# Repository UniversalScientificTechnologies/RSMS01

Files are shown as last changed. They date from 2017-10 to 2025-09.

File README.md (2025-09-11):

# RSMS01 – UHF Radio Storm Monitoring Station (with VLF trigger)

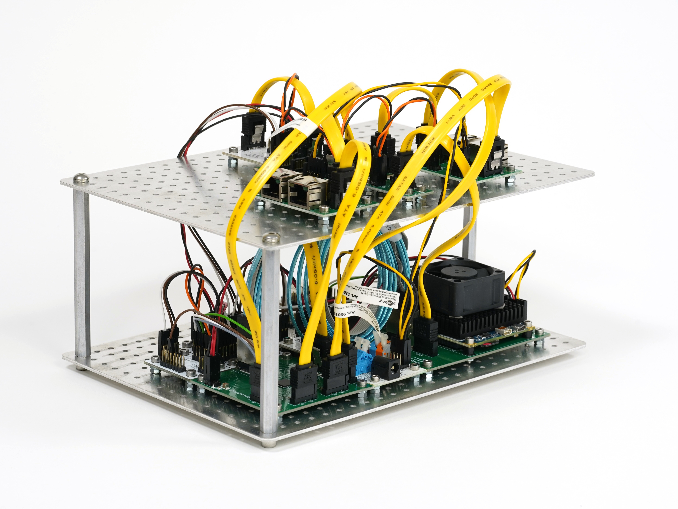
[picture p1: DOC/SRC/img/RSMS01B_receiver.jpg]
Lightning signal receiver RSMS01B UHF lightnig signal receiver RSMS01B


> Mobile/portable lightning receiver for research-grade event capture. Records a full 10 MHz RF segment around \~400 MHz from an antenna array, time‑stamped and triggered by a VLF front‑end. A closely related VLF station [RSMS02](https://github.com/UniversalScientificTechnologies/RSMS02) shares most subsystems.

## Overview

RSMS01 is a mobile UHF lightning observation station designed for ground deployments (rooftop platforms on vehicles, or fixed). It complements a VLF receiver ([RSMS02](https://github.com/UniversalScientificTechnologies/RSMS02)) used for robust triggering and coarse detection. Together, both instruments capture long, contiguous, time‑synchronized RF segments of lightning activity for detailed post‑processing (TDoA, interferometry/DOA, correlation to optical/EFM/radiation sensors).

Why **UHF + VLF**:

* **VLF ( 20 kHz  to 500 kHz):** strong from the main/lightning channel; excellent for reliable triggering and long‑range detection.
* **UHF (\~370–406 MHz):** rich in initial breakdown/leader structure; less contaminated by distant channel energy; ideal for fine‑scale timing/structure.

## Receiver Features

* **10 MHz contiguous RF capture** around \~400 MHz (tunable within local RFI constraints).
* **Antenna array** (4× QFH elements) enabling future DOA/interferometric processing; current release stores synchronous per‑element I/Q streams.
* **Event‑based recording**: up to **\~1.45 s** per trigger with configurable pre/post buffers from a continuous ring‑buffer.
* **GNSS‑disciplined timing**: PPS‑derived time marks + sample indexes embedded per event for millisecond‑class absolute timing after reconstruction.
* **VLF‑driven triggering** with adjustable *Time‑over‑Threshold* (pulse width + level) parameters for noisy environments.
* **Stationary or mobile** operation: roof‑rack plywood deck or fixed mast mount; active front‑ends in sealed housings.
* **Live spectrum/waterfall** via [fosphor](https://osmocom.org/projects/sdr/wiki/fosphor).

## System architecture

Block diagram of the UHF radio receiver used in the experiment. The internals of the active antenna mounted on the car roof are depicted in the blue bubbles on the left part of the schematics.

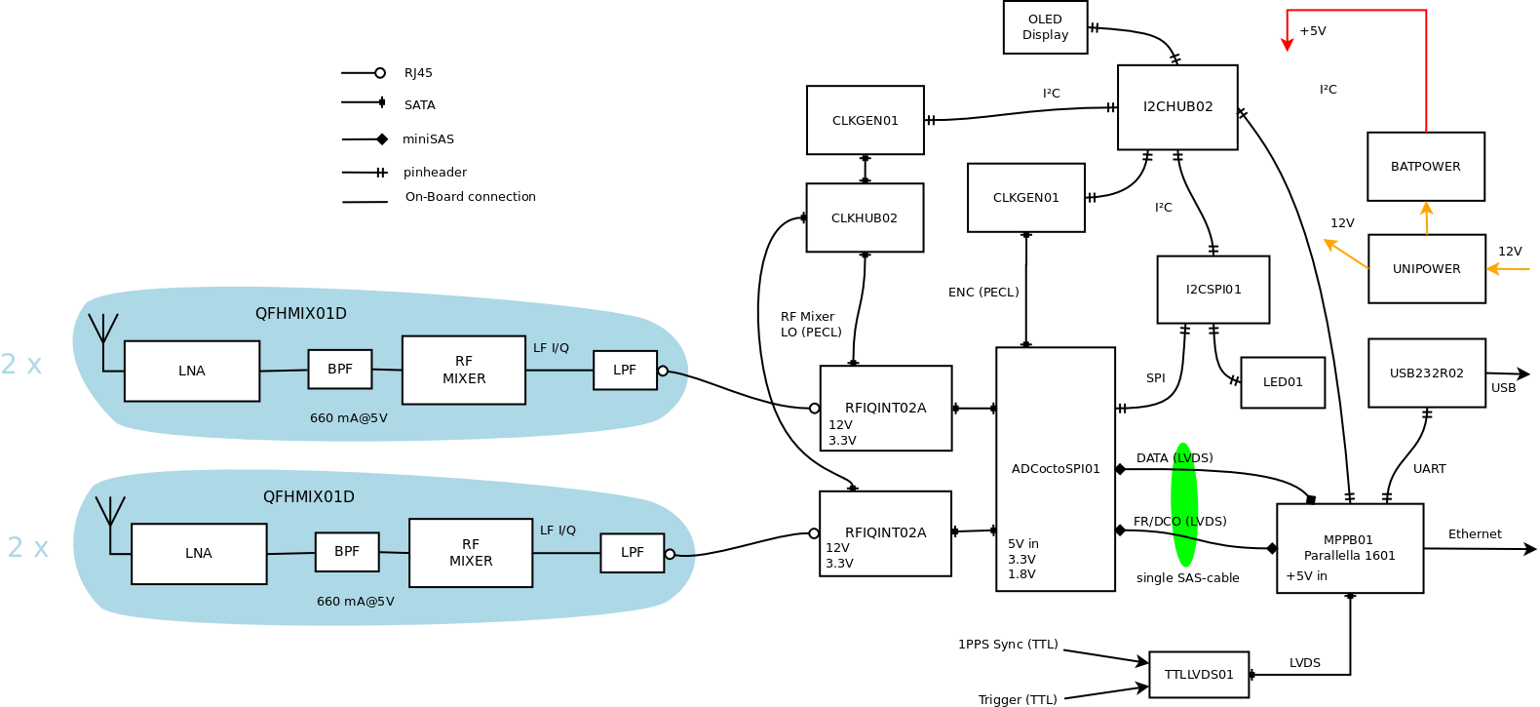
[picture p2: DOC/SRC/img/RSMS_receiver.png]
Station block schamatics Overview of interconnection of station components


The station is interconnected with RSMS02 to get a trigger from stronger VLF signals. Therefore, the high-level system schematic looks like the following (the repeated signal strings are omitted).  

```mermaid
flowchart LR
  subgraph UHF_Antenna_Array [UHF Antenna Array]
    Q1[QFH #1]
    Q2[QFH #2]
    Q3[QFH #3]
    Q4[QFH #4]
  end

  subgraph RF_FrontEnds [Active RF front-ends]
    direction LR
    BPF1[BPF] --> LNA1[LNA] --> BPF2[BPF] --> LNA2[LNA] --> MIX[Mixer LO] --> LPF[LPF Line-Driver]
  end

  Q1 & Q2 & Q3 & Q4 --> RF_FrontEnds

  RF_FrontEnds -- "I/Q differential over CAT6" --> ADCs[12‑bit ADCs @ 10 MS/s per I/Q]
  ADCs --> RBUF[Ring buffer & trigger logic]
  RBUF --> STORE[Storage of ~1.45 s per event]
  PPS[GNSS PPS time‑mark capture] --> RBUF

  subgraph RSMS02 [VLF station RSMS02]
    VLFANT[STP loop antenna array] --> VLFADC[ADC] --> VLFTRIG[FPGA trigger threshold + min-width]
  end
  VLFTRIG -- "Trigger out" --> RBUF

```

### RF front‑end (per QFH element)

* **Filters & gain chain:** BPF → LNA (low NF/high OIP3) → BPF → LNA (gain/dynamic range).
* **Down‑conversion:** high‑linearity UHF mixer with low‑jitter LO distribution.
* **Baseband transport:** anti‑alias LPF (\~5 MHz) and differential line driver; 100 Ω differential over CAT6 to the base unit.
* **Shielding/EMI:** aluminum housings, differential LVPECL LO distribution, short RF paths.

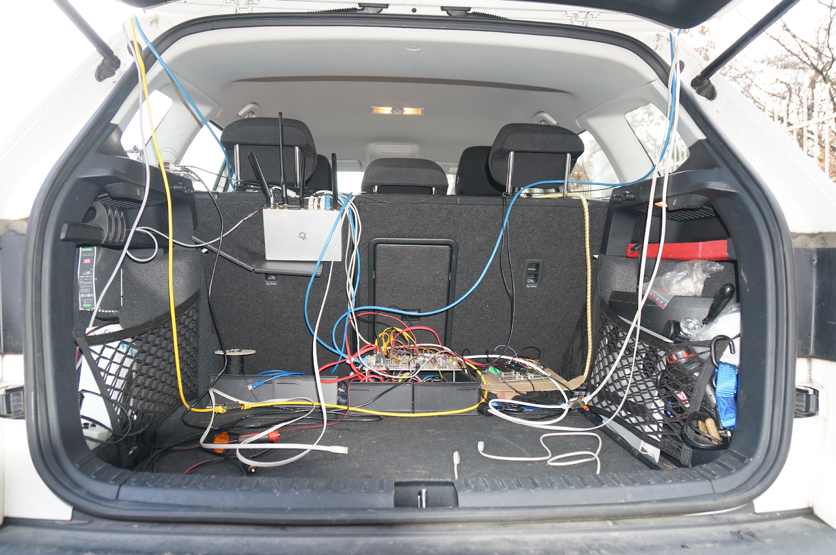
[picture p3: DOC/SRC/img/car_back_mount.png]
Mobile receiver mounted


### Antenna array

* **QFH (Quadrifilar Helix)** elements with inherent quadrature ports → natural I/Q pairing and near‑omnidirectional, circularly‑polarized response across the band. Four elements are arranged in a compact square roof deck.

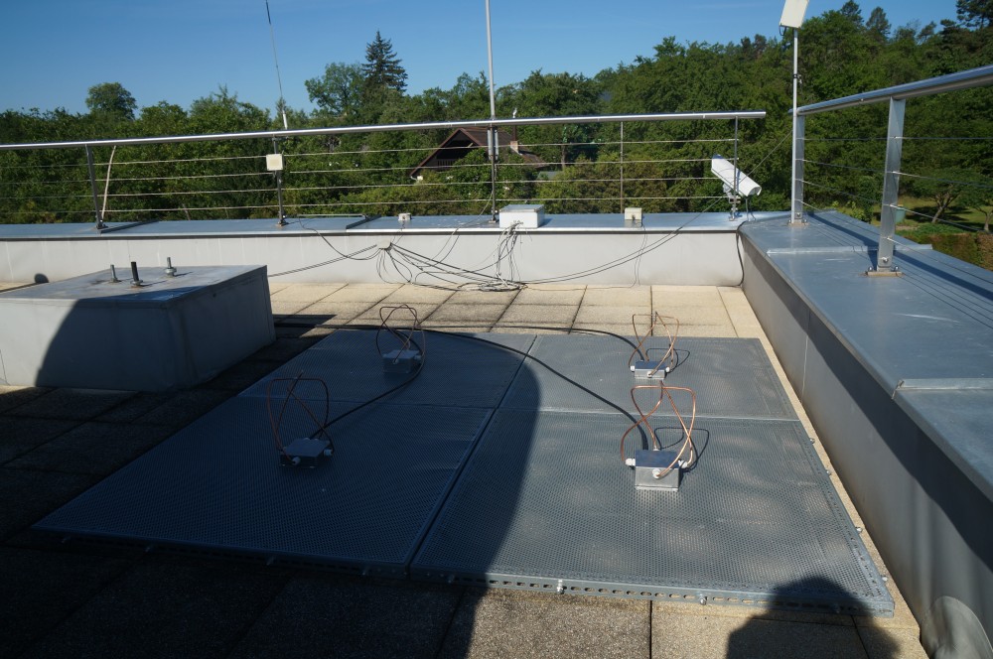
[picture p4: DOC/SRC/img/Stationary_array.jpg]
Stationary antenna array Stationary antenna array on an observatory roof


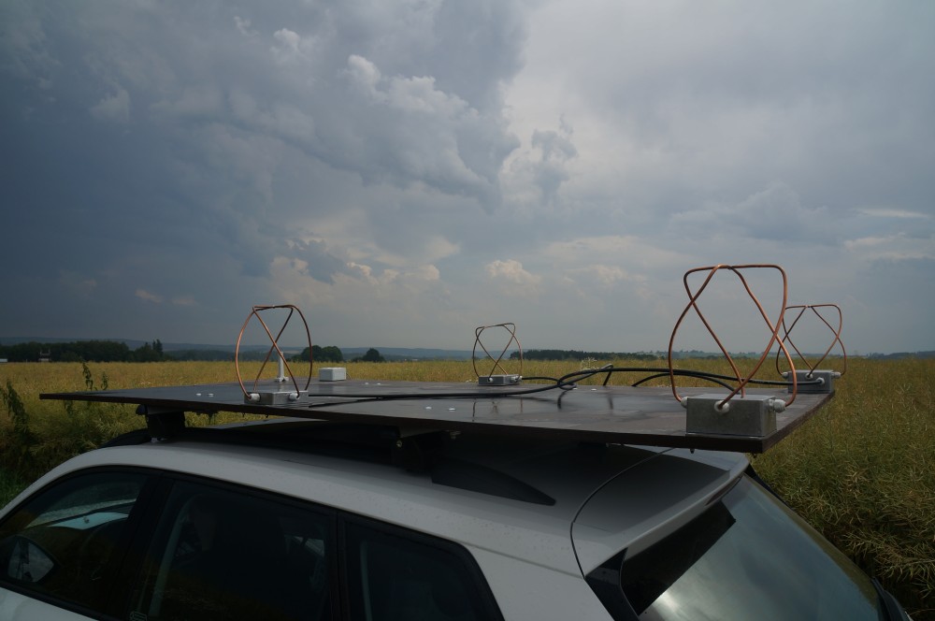
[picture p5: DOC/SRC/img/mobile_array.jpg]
Mobile antenna array Mobile antenna array on a car roof


## Triggering & timing

### VLF trigger (RSMS02)

* Adjustable level and minimum pulse width (typ. starting points: *level 10–30 mV*, *width 5–20 µs*) for Time‑over‑Threshold detection.
* Robust to impulsive RFI compared to pure thresholding; suitable for mobile, semi‑urban sites.

### UHF capture (RSMS01)

* External trigger from VLF arm latches the ring buffer; you get configurable pre‑trigger and post‑trigger blocks.
* Absolute timing: Each event stores sample counters + several last PPS time‑marks → reconstruct UTC for every sample during post‑processing.

## Frequency planning & bandwidth

* **Nominal UHF band:** **\~370–406 MHz** (select center to avoid strong local services; keep 10 MHz window clean). 10 MHz comfortably spans dominant lightning UHF content while keeping data rates manageable and front‑ends practical.
* **VLF sensors:** shielded STP‑loop antennas; mount orthogonally; keep inverter/SMPS noise away from cabling where possible.

---

## Visualization

> Linux host with recent CUDA/OpenCL drivers recommended for fosphor. Example packages (Debian/Ubuntu). The device uses [fosphor](https://osmocom.org/projects/sdr/wiki/fosphor) for real-time spectral visualization.

```bash
sudo apt-get install nvidia-opencl-dev opencl-headers
```

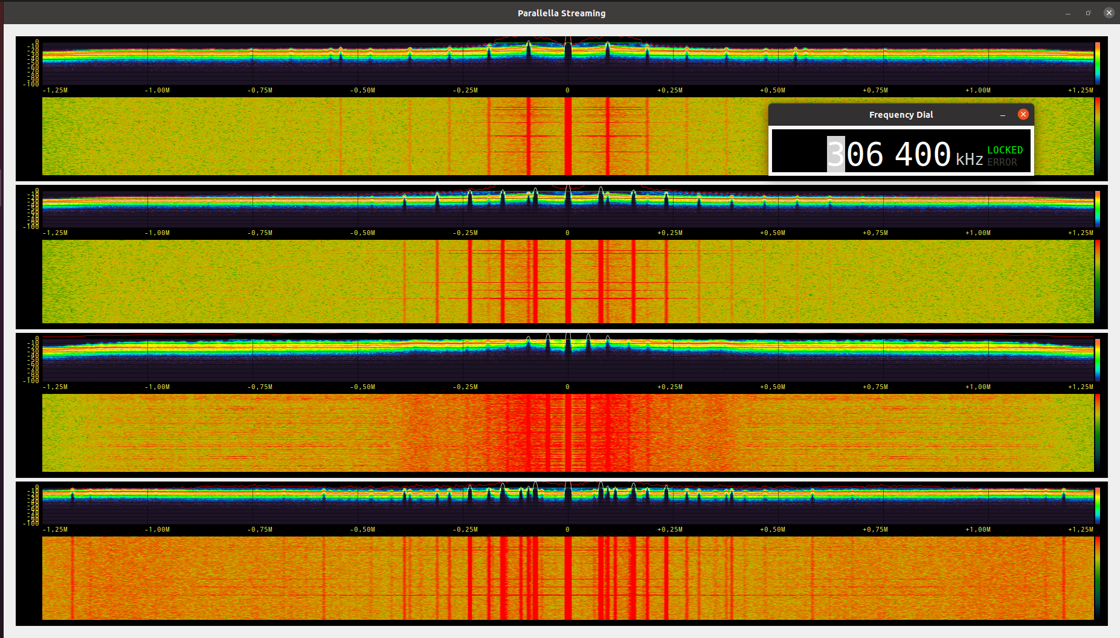
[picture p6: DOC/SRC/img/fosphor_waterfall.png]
Fosphor waterfall for antenna array


1. **Assemble hardware**

   * Mount 4× QFH elements on a rigid non‑conductive deck (vehicle roof or mast).
   * Install active RF front‑ends at the antenna bases; route CAT6 to base unit.
   * Mount VLF STP‑loop frame (orthogonal axes), route to RSMS02
   * Connect GNSS antenna for PPS to the base unit.

2. **Connect & power**

   * Prefer battery/linear supplies; if an inverter is unavoidable, isolate and test for conducted/ radiated noise before storm operations.

3. **Run**

   * Start the VLF UI, set initial level/width; verify trigger with observed lightning.
   * Start UHF recorder; confirm ring‑buffer, PPS lock, and per‑element I/Q streams.
   * Launch visualization for situational awareness; keep gain conservative to avoid ADC clipping.

## Data format & post‑processing

Each event contains:

* **Per‑element I/Q** streams (12‑bit, 10 MS/s, 10 MHz complex BW) for the full capture window (\~1.45 s typical).
* **Timing metadata:** sample indices and recent PPS time‑marks → reconstruct absolute UTC.
* **Trigger metadata:** VLF detector parameters at trigger time.

#### Relevant scientific publications

  * [In situ ground-based mobile measurement of lightning events above central Europe](https://amt.copernicus.org/articles/16/547/2023/)
  * [Radio Detection of Electromagnetic Phenomena in the Atmosphere - Integrating Advanced Instrumentation and UAVs for Enhanced Atmospheric Research](https://dspace.cvut.cz/handle/10467/120570) - Dissertation thesis

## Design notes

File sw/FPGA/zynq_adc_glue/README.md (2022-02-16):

These are sources for the programmable logic layer between the ADCs and the Parallella's ARM processor.

## Build Prerequisities

 * [Xilinx Vivado](https://www.xilinx.com/products/design-tools/vivado.html) v2018.2
   The free WebPACK edition works. Note the version.

 * [Device Tree Compiler](https://git.kernel.org/pub/scm/utils/dtc/dtc.git/plain/Documentation/manual.txt)
   Converts device trees between their source text and blob format. Usually packaged as 'dtc'.

Make sure that the binaries `vivado` and `dtc` are in `PATH`.

## Why There's No Project File

Vivado projects are not well-suited for being managed by a version control system. For this reason, there's 'create_project.tcl' instead, which is a Vivado TCL script for recreating the project from scratch. Vivado generates these scripts upon request. The TCL script contains the build settings and the block design in a diffable text format. More about this in Xilinx's [application note](https://www.xilinx.com/support/documentation/application_notes/xapp1165.pdf).

## make Commands

Currently the bitfile cannot be produced by calling `make` alone. After checkout and recreation of the Vivado project file, you must use the GUI to export the `glue` block design as an IP core, say into `../ip_repo`, and then you must update reference to this IP core from within the `top_block` block design. Then, the bitfile can be build as below or with the GUI.

	make

Generates all the build products. It starts with the Vivado project, which is generated in 'vivado_prj/', then it builds the bitfile as 'build/zynq_adc_glue.bit', and finally converts the bitfile into a 'build/parallella.bit.bin', which can be used to program the Zynq. Also creates the device tree blob.

	make vivado_prj/system.xpr

Creates the Vivado project only. The project can be then opened with the Vivado GUI.

	make clean

Removes both the build products in 'build/' and all the project files in 'vivado_prj/'.

	make write_project_script

This rewrites 'create_project.tcl' according to the local Vivado project so that changes made there can be commited.

## Device Tree

Linux is informed of the relevant Zynq configuration via a so-called [device tree](https://www.kernel.org/doc/Documentation/devicetree/usage-model.txt). For reasons that haven't been searched for yet, the configuration in the produced bitfile is not compatible with the one described by Adapteva's device trees to the point that Linux freezes during boot. 'devicetree.dts' contains source for a custom device tree based on the one Xilinx's tools [generated for the design](http://www.wiki.xilinx.com/Build+Device+Tree+Blob). Besides making the system bootable, this device tree also:

 * excludes the top 256 MiB of memory from kernel usage, so that it can be safely used as a target for DMA transfers
 * enables the FCLK3 clock, which was formerly used by the programmable logic when generating mock data

To use the custom device tree, it first needs to be compiled into a blob by the Device Tree Compiler. The makefile has a rule for that with the resultant blob being at 'build/devicetree.dtb'.

## Testing the Result

To boot the Parallella with the custom PL configuration, one replaces `parallella.bit.bin` and `devicetree.dtb` on the boot partition with the build results from `build/`.

To trigger a DMA transfer and, optionally, retrieve the transferred data, use the `dma_test` tool.

	Usage: dma_test [-r] [-m] [-b NO_OF_BYTES] [-f FILENAME]

		-r  dumps registers and exits
		-m  enables mock data source
		-b  burst mode, transfers the specified amount of bytes and exits
			(supports k and m suffixes for units of 1024 and 1024^2)
		-f  writes the transferred data to the given file, '-' for stdout.
			in burst mode, slow writes won't cause dropped frames

Successful continuous transfer looks like this:

	# ./dma_test
	pl_design_id=0xd5170001
	(after reset) s2mm_dmasr=0x10009
	(after s2mm_dmacr write) s2mm_dmasr=0x10008
	transferred=0x8a00000 counter=0x008a02a5 overflow=0x00000000

(The last line gets updated.) 'transferred' refers to transferred bytes. 'counter' is a number of frames counted in the logic. 'overflow' is the number of dropped frames due to FIFO overflow. The latter two correspond to the registers explained below.

For a quick look at the samples there's `tools/samples_plot.py`. Try the following on a remote computer (remote to Parallella):

	$ ssh PARALLELLA_HOSTNAME ./dma_test -f - -b 1m | ./tools/samples_plot.py

This assumes `dma_test` lies compiled in the home directory on Parallella.

## Software Side Interface

The software running on Zynq's ARM communicates with the programmable logic design via two sets of registers that are mapped into the physical address space of the CPU. The first set starts at `0x60000000`, and these are registers of an [off-the-shelf Xilinx DMA engine block](https://www.xilinx.com/support/documentation/ip_documentation/axi_dma/v7_1/pg021_axi_dma.pdf). The second set is one page above, at `0x60001000`, and these are our custom registers.

The software uses the registers of the DMA engine to arrange for the transfer of data into RAM. The second set of registers is then used to reset, enable and check the status of the logic that feeds the DMA engine with data. This logic ("our peripheral") receives the frames, filters them, buffers them in a FIFO and serializes them for transfer by the DMA engine. The data is fed to the DMA engine as an unannotated stream of bytes and their placement into memory is completely subject to the software's configuration of the engine.

The DMA engine has been synthesized with the Gather/Scatter Mode enabled and with the buffer size field of one descriptor being 24 bits wide. These parameters influence how the engine should be configured by software.

### The Custom Set of Registers

All registers are little endian.

| Offset | Byte Length | R/RW | Description |
| ---:| ---:| ---- | --- |
|  +0x00 | 4 | R | ID of the PL design (0xd5170006) |
|  +0x04 | 4 | RW | Control register |
|  +0x08 | 4 | R | Number of frames received |
|  +0x0c | 4 | R | Number of frames dropped due to FIFO overflow |
|  +0x10 | 4 | R | Reserved for error flags |
|  +0x14 | 4 | R | Timing of the last captured SYNC edge |

The bits of the control register have the following meaning:

| Bit Pos. (starts from 0) | Description |
| ---:| --- |
| 0 | Sample Input Enable |
| 1 | Pipeline Reset |
| 8 | Filter Bypass Enable |
| 9 | SYNC Edge Select (set for falling edge, unset for rising edge) |

The sample input enable influences whether new samples received on the ADC data lines enter the programmable logic pipeline.

The pipeline reset clears the FIFO contents, resets the FIR filter inner state and other pipeline state. The reset bit is deasserted automatically after a few cycles. The pipeline reset does not clear the contents of the control register.

### Recommended Programming Sequence

 1. reset the pipeline without enabling the sample input
 2. prepare the DMA engine for transfer so that it accepts data
 3. enable sample input

## Data Format

Samples from each of the eight 12-bit ADC channels are zero-padded from the LSB side to 2 bytes. These 2 bytes per channel are concatenated in little-endian into a 16-byte frame. The transferred data is a stream of these frames. After the reset of our peripheral, the transfer starts with a new frame and, if overflow occurs, whole frames are dropped. Therefore the software should never get desynchronized with respect to the byte-within-frame position.

## Synchronization

The logic design has an input port, called SYNC, dedicated to time synchronization. This input port is sampled as are the ADC data lines, on each edge of the ADC bit clock. Once an edge on the SYNC input with the selected-for polarity is detected, the position of the edge in the stream of frames is noted. This position includes both an absolute frame number -- that is, absolute number since pipeline reset -- and a fractional part signifying position of the edge within one ADC sample period. The positional information is only retained for the last detected edge and exposed in a register. This register is doubleword-long and is at +0x14.

Top three bytes of the register contain the absolute frame number modulo 2^24. The bottom byte of the register contains the fractional part. The fractional part is in units of 1/12 of undecimated sample period. The fractional part has values in the range [0, 48) for FIR enabled and [0, 12) for FIR disabled.

 * *FIR bypassed:* If FIR filter is bypassed, the absolute frame number points to the frame whose bits were being transferred when the edge was detected. The fractional part then specifies which particular bit has been sampled when the transition on the SYNC input was observed. Starting with fractional part equal to zero, in which case the last bit has been sampled, up to fractional part being eleven, in which case the first bit has been sampled when the transition was observed. See fig. 1 in the AFE5801 datasheet. If, for example, fractional part equals 3, the transition must have occured between sampling of the D7 and D8 bit. Note that ADC is in LSB-first-mode.

 * *FIR in the loop*: If FIR filter is enabled, the position as seen in register +0x14 accounts for decimation. The frame number is counted in decimated frames and the fractional part is in units of 1/48 of sample period of the decimated stream. Much in the same way as with FIR bypassed, an increasing fractional part shifts occurence of the edge in the opposite direction compared to increasing frame number.

## Bugs & TODO

 * Test peripherals. Do they work properly with our design? (SPI, I2C, something else also?) I have tried to copy from Adapteva's design in areas that are not relevant to our goal. Let's check that nothing is broken.

 * Look into the device tree incompatibility.

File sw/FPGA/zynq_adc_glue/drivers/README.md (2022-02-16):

## dma_test

	# ./dma_test -h
	./dma_test: invalid option -- 'h'
	Usage: dma_test [-r] [-m] [-b NO_OF_BYTES] [-f FILENAME]

		-r  dumps registers and exits
		-m  enables mock data source
		-b  burst mode, transfers the specified amount of bytes and exits
		    (supports k and m suffixes for units of 1024 and 1024^2)
		-f  writes the transferred data to the given file, '-' for stdout.
		    in burst mode, slow writes won't cause dropped frames

## capture_on_sync

`capture_on_sync`, as the name suggests, repeatedly captures a short period of frames around a SYNC edge. The frames go to standard output, from where they should be saved to a file. Captured frames can then be plotted with `capture_on_sync_plot.py`. Pass the command line flag `-c 256` to bypass FIR. 

	$ ssh PARALLELLA drivers/capture_on_sync -c 256 > captures
	... (Ctrl+C)
	$ ./capture_on_sync_plot.py captures 0 1 # plot first and second channel

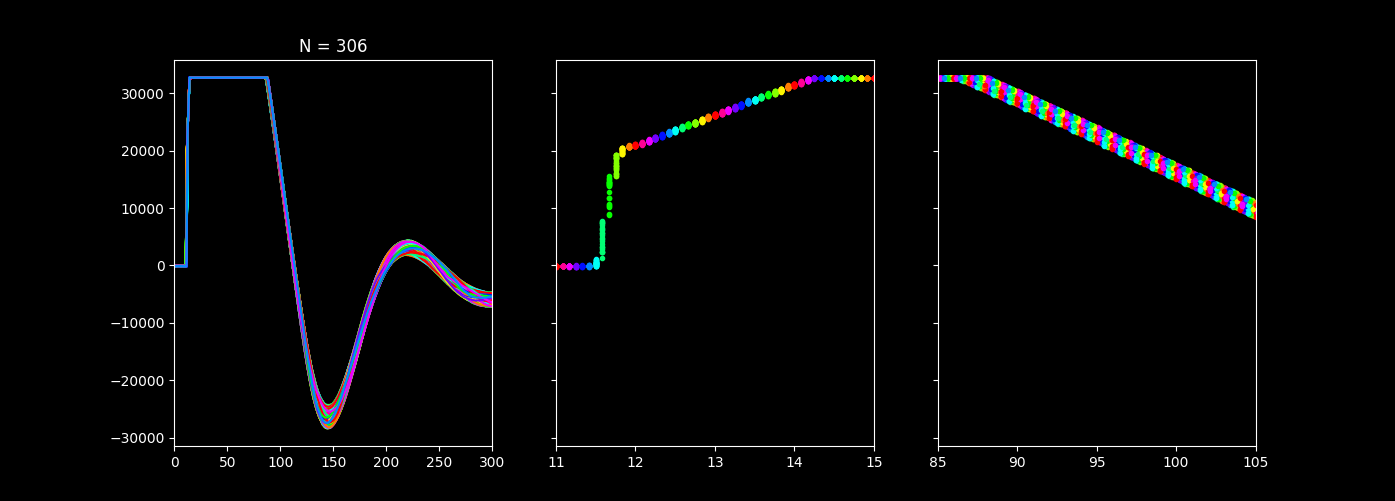
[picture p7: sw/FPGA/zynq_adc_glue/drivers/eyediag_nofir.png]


## trigger

`trigger` serves to capture a burst of samples before and after being triggered. Triggering is done via the differential pair SYNC_B on the parallella reduction board.

SYNC_B is routed through programmable logic to an GPIO peripherial. The GPIO pin is controlled through the `/sys` filesystem. To populate the relevant files, run:

	# echo 960 > /sys/class/gpio/export

`trigger` can then be used.

	# ./trigger -h
	Usage of ./trigger:
	  -depth int
	    	depth of the descriptor chain maintained for the DMA engine (default 10)
	  -nofir
	    	configure logic to bypass the FIR filter
	  -post int
	    	no. of MiB blocks to save that were sampled after the trigger (default 4)
	  -pre int
	    	no. of MiB blocks to save that were sampled before the trigger (default 4)
	  -recdir string
	    	path to directory to save the recordings in (missing nodes will be created) (default "rec")

Recordings can be plotted with `trigger_plot.py`.

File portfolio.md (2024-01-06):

---
title: "Radio storm monitoring station"
excerpt: "RSMS01 is radio receiver for reception of signals produced by lightning discharges"
header:
  image: products/RSMS01/DOC/SRC/img/RSMS01B_receiver.jpg
  teaser: products/RSMS01/DOC/SRC/img/RSMS01B_receiver.jpg
  overlay_color: "#000"
  overlay_filter: "0.5"
  overlay_image: products/RSMS01/DOC/SRC/img/RSMS01B_receiver.jpg
---

Lightning signal receiver RSMS01B UHF lightnig signal receiver RSMS01B

Mobile UHF lightning mapping station based on an antenna array. The device is essential tool for lightning research.
The array could either be stationary or mobile, mounted on the car roof. The receiver is able to record an radio waveform of lightning before of trigger signal. 

Stationary antenna array Stationary antenna array on an observatory roof

Mobile antenna array Mobile antenna array on a car roof

#### Block Schematics

Station block schematics Overview of interconnection of station components

#### Visualization

The device uses [fosphor](https://osmocom.org/projects/sdr/wiki/fosphor) for real-time spectral visualization.

Fosphor waterfall for antenna array

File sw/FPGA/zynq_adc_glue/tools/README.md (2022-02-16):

# Tools

## afe5801_conf.py

`afe5801_conf.py` configures the ADC by writing to its registers over SPI. It resets the ADC to its default configuration and then, if an argument is passed, enables one of test patterns to be output on ADC data lines. The argument is the value, in binary, to be written to the appropriate register bitrange. See [AFE5801 datasheet](https://github.com/toxygen/DENGS/tree/master/HW/modules/ADCoctoSPI01A/DOC/pdf/AFE5801.pdf), p. 24, for the options.

### Example

Datasheet says: PATTERN_MODE equal to 101 makes the output of the device toggle between two consecutive codes. On the nth sample clock, the data is 0000 0000 0000, and on the following one (nth + 1), it is 1111 1111 1111.

	root@localhost:~# ./afe5801_conf.py 101
	resetting
	{'port': None}
	(u'00A59CB6', <type 'unicode'>)
	setting PATTERN_MODE to 0x5
	        reg[1] = 0x0
	        reg[2] = 0xa000
	        reg[3] = 0x0
	        reg[4] = 0x0
	        reg[5] = 0x0
	        reg[6] = 0x0
	root@localhost:~# ./dma_test -b 256 -f - | xxd -g 2 -e -b -c 16
	pl_design_id=0xd5170003
	(after reset) s2mm_dmasr=0x10009
	(after s2mm_dmacr write) s2mm_dmasr=0x10008
	transferred=0x100 counter=0x000029ea overflow=0x000027d9
	00000000: 0000000000000000 0000000000000000 0000000000000000 0000000000000000 0000000000000000 0000000000000000 0000000000000000 0000000000000000  ................
	00000010: 1111000011111111 1111000011111111 1111000011111111 1111000011111111 1111000011111111 1111000011111111 1111000011111111 1111000011111111  ................
	00000020: 0000000000000000 0000000000000000 0000000000000000 0000000000000000 0000000000000000 0000000000000000 0000000000000000 0000000000000000  ................
	00000030: 1111000011111111 1111000011111111 1111000011111111 1111000011111111 1111000011111111 1111000011111111 1111000011111111 1111000011111111  ................
	00000040: 0000000000000000 0000000000000000 0000000000000000 0000000000000000 0000000000000000 0000000000000000 0000000000000000 0000000000000000  ................
	00000050: 1111000011111111 1111000011111111 1111000011111111 1111000011111111 1111000011111111 1111000011111111 1111000011111111 1111000011111111  ................
	00000060: 0000000000000000 0000000000000000 0000000000000000 0000000000000000 0000000000000000 0000000000000000 0000000000000000 0000000000000000  ................
	00000070: 1111000011111111 1111000011111111 1111000011111111 1111000011111111 1111000011111111 1111000011111111 1111000011111111 1111000011111111  ................
	00000080: 0000000000000000 0000000000000000 0000000000000000 0000000000000000 0000000000000000 0000000000000000 0000000000000000 0000000000000000  ................
	00000090: 1111000011111111 1111000011111111 1111000011111111 1111000011111111 1111000011111111 1111000011111111 1111000011111111 1111000011111111  ................
	000000a0: 0000000000000000 0000000000000000 0000000000000000 0000000000000000 0000000000000000 0000000000000000 0000000000000000 0000000000000000  ................
	000000b0: 1111000011111111 1111000011111111 1111000011111111 1111000011111111 1111000011111111 1111000011111111 1111000011111111 1111000011111111  ................
	000000c0: 0000000000000000 0000000000000000 0000000000000000 0000000000000000 0000000000000000 0000000000000000 0000000000000000 0000000000000000  ................
	000000d0: 1111000011111111 1111000011111111 1111000011111111 1111000011111111 1111000011111111 1111000011111111 1111000011111111 1111000011111111  ................
	000000e0: 0000000000000000 0000000000000000 0000000000000000 0000000000000000 0000000000000000 0000000000000000 0000000000000000 0000000000000000  ................
	000000f0: 1111000011111111 1111000011111111 1111000011111111 1111000011111111 1111000011111111 1111000011111111 1111000011111111 1111000011111111  ................

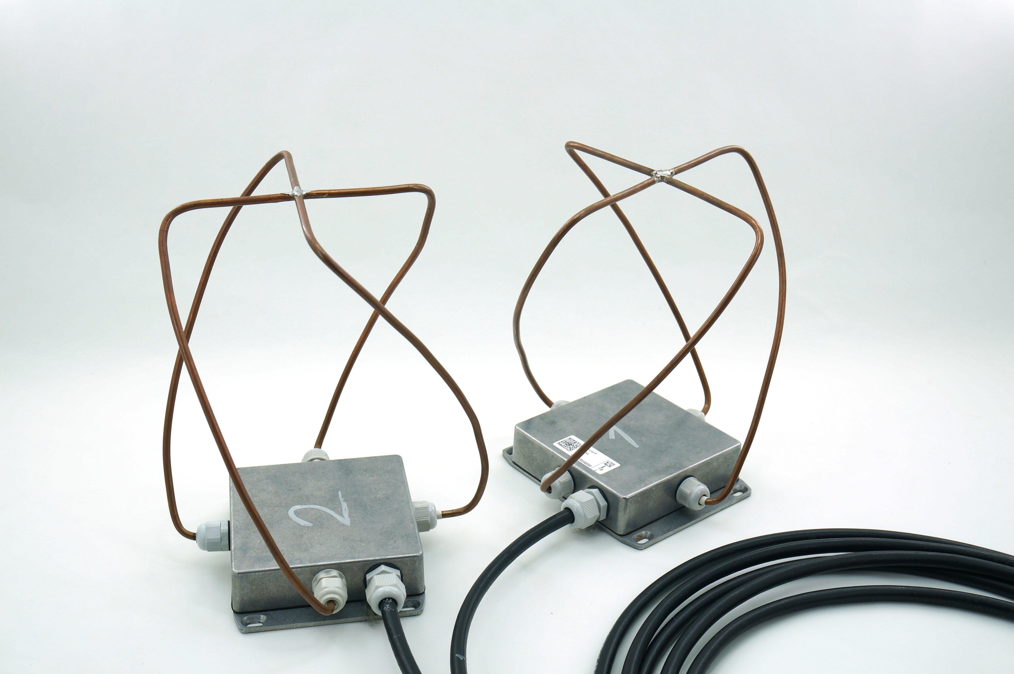
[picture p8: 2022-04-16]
DOC/SRC/img/QFH_antenna.jpg

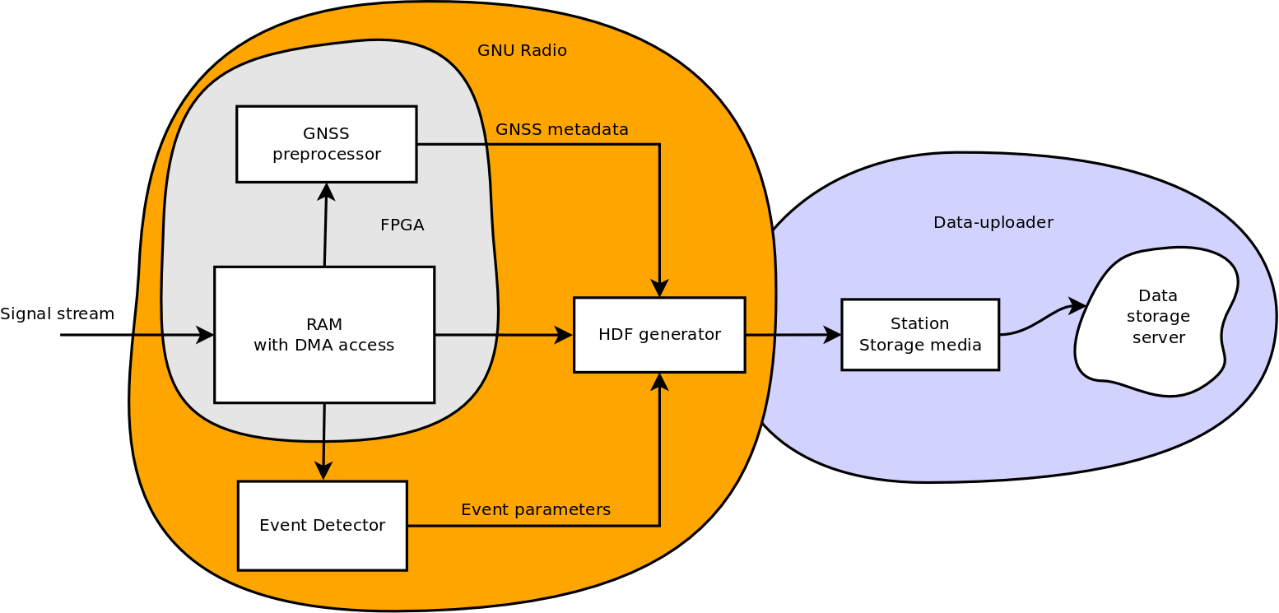
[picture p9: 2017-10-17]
DOC/SRC/img/Signal_processig.png

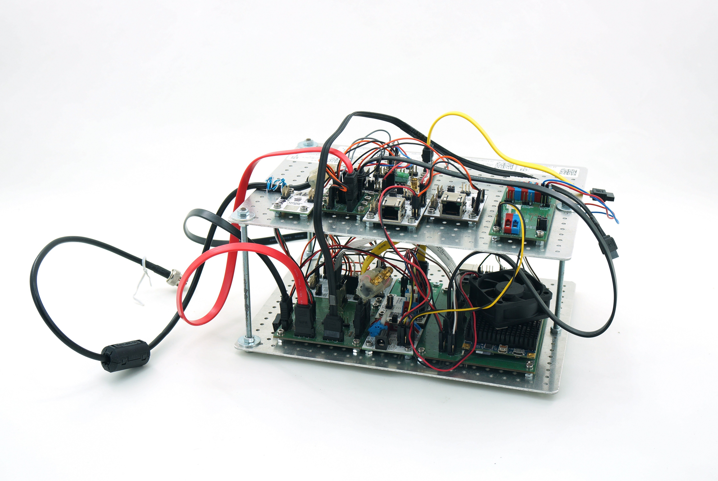
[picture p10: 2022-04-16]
DOC/SRC/img/RSMS_receiver.jpg

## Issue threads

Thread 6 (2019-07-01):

Lighning modul připojit na delší kabel

kaklik, 2019-07-01:
lightning modul umístěný na desce stanice nemá dostatečnou citlivost a navíc je zarušený měničem ve stanici.

Řešením je použití [ I2CDIFF modulu](https://mlab.cz/module/I2CDIFF01B).

kaklik, 2020-08-05:
Modul [LIGHTNING01A](https://mlab.cz/module/LIGHTNING01A) byl připojen na delší kabel přes [I2CDIFF01B](https://mlab.cz/module/I2CDIFF01B) po [opravě chyby s přenosem interruptu](https://github.com/MLAB-project/Modules/issues/31).

Closed 2020-08-05.

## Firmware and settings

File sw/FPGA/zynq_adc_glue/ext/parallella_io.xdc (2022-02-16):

#######################
# Configuration Pins
#######################
set_property CFGBVS VCCO [current_design]
set_property CONFIG_VOLTAGE 3.3 [current_design]

#######################
# HDMI constraints
#######################
#TODO: Include for hdmi design
#set_property IOSTANDARD LVCMOS25 [get_ports {hdmi_*}]
#set_property PACKAGE_PIN Y18 [get_ports {hdmi_d[8]}]
#set_property PACKAGE_PIN W18 [get_ports {hdmi_d[9]}]
#set_property PACKAGE_PIN V18 [get_ports {hdmi_d[10]}]
#set_property PACKAGE_PIN V15 [get_ports {hdmi_d[11]}]
#set_property PACKAGE_PIN R18 [get_ports {hdmi_d[12]}]
#set_property PACKAGE_PIN P18 [get_ports {hdmi_d[13]}]
#set_property PACKAGE_PIN Y19 [get_ports {hdmi_d[14]}]
#set_property PACKAGE_PIN W19 [get_ports {hdmi_d[15]}]
#set_property PACKAGE_PIN W15 [get_ports {hdmi_d[16]}]
#set_property PACKAGE_PIN T19 [get_ports {hdmi_d[17]}]
#set_property PACKAGE_PIN R19 [get_ports {hdmi_d[18]}]
#set_property PACKAGE_PIN P19 [get_ports {hdmi_d[19]}]
#set_property PACKAGE_PIN W20 [get_ports {hdmi_d[20]}]
#set_property PACKAGE_PIN V20 [get_ports {hdmi_d[21]}]
#set_property PACKAGE_PIN U20 [get_ports {hdmi_d[22]}]
#set_property PACKAGE_PIN T20 [get_ports {hdmi_d[23]}]
#set_property PACKAGE_PIN R17 [get_ports hdmi_clk]
#set_property PACKAGE_PIN V17 [get_ports hdmi_vsync]
#set_property PACKAGE_PIN T17 [get_ports hdmi_hsync]
#set_property PACKAGE_PIN Y17 [get_ports hdmi_de]
#set_property PACKAGE_PIN Y16 [get_ports hdmi_spdif]
#set_property PACKAGE_PIN P20 [get_ports hdmi_int]

#####################
# I2C
#####################
set_property IOSTANDARD LVCMOS25 [get_ports i2c_*]
set_property PACKAGE_PIN N18 [get_ports i2c_scl]
set_property PACKAGE_PIN N17 [get_ports i2c_sda]

#####################
# Epiphany Reset
#####################
#set_property IOSTANDARD LVCMOS25 [get_ports {chip_nreset}]
#set_property PACKAGE_PIN G14 [get_ports {chip_nreset}]

#####################
# Epiphany Clock
#####################
#set_property IOSTANDARD LVDS_25 [get_ports {cclk*}]
#set_property PACKAGE_PIN H17 [get_ports cclk_n]

#####################
# Epiphany TX
#####################
#set_property IOSTANDARD LVDS_25 [get_ports {txo*}]
#set_property IOSTANDARD LVDS_25 [get_ports {txi*}]
#set_property PACKAGE_PIN F17 [get_ports txo_lclk_n]
#set_property PACKAGE_PIN A20 [get_ports {txo_data_n[0]}]
#set_property PACKAGE_PIN B20 [get_ports {txo_data_n[1]}]
#set_property PACKAGE_PIN D20 [get_ports {txo_data_n[2]}]
#set_property PACKAGE_PIN E19 [get_ports {txo_data_n[3]}]
#set_property PACKAGE_PIN D18 [get_ports {txo_data_n[4]}]
#set_property PACKAGE_PIN F20 [get_ports {txo_data_n[5]}]
#set_property PACKAGE_PIN G18 [get_ports {txo_data_n[6]}]
#set_property PACKAGE_PIN G20 [get_ports {txo_data_n[7]}]
#set_property PACKAGE_PIN G15 [get_ports txo_frame_n]
#set_property PACKAGE_PIN H18 [get_ports txi_wr_wait_n]

#####################
# Wait signals
#####################
#set_property IOSTANDARD LVCMOS25 [get_ports {txi_rd_wait_*}]
#set_property PACKAGE_PIN J15 [get_ports txi_rd_wait_p]


#####################
# Epiphany RX
#####################
#set_property IOSTANDARD LVDS_25 [get_ports {rx*}]
#set_property PACKAGE_PIN K18 [get_ports rxi_lclk_n]
#set_property PACKAGE_PIN J19 [get_ports {rxi_data_n[0]}]
#set_property PACKAGE_PIN L15 [get_ports {rxi_data_n[1]}]
#set_property PACKAGE_PIN L17 [get_ports {rxi_data_n[2]}]
#set_property PACKAGE_PIN M15 [get_ports {rxi_data_n[3]}]
#set_property PACKAGE_PIN L20 [get_ports {rxi_data_n[4]}]
#set_property PACKAGE_PIN M20 [get_ports {rxi_data_n[5]}]
#set_property PACKAGE_PIN M18 [get_ports {rxi_data_n[6]}]
#set_property PACKAGE_PIN N16 [get_ports {rxi_data_n[7]}]
#set_property PACKAGE_PIN H20 [get_ports rxi_frame_n]
#set_property PACKAGE_PIN J14 [get_ports rxo_rd_wait_n]
#set_property PACKAGE_PIN J16 [get_ports rxo_wr_wait_n]

#######################
# GPIO
#  First 12 pairs are present on all parts, next 12 on 7020 only
#######################
#set_property IOSTANDARD LVCMOS25 [get_ports {gpio*}]
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

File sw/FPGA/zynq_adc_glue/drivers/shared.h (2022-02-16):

/*
	The DMA block is called 'AXI DMA v7.1', documentation can be found here:
	https://www.xilinx.com/support/documentation/ip_documentation/axi_dma/v7_1/pg021_axi_dma.pdf

	It is configured for descriptors with 24-bit wide buffer lengths (out of the 26-bit maximum).
*/

#include <sys/mman.h>
#include <fcntl.h>
#include <unistd.h>
#include <stdio.h>
#include <stdint.h>
#include <stdlib.h>
#include <string.h>
#include <assert.h>
#include <errno.h>
#include <err.h>

/* for printing uint64 */
#define __STDC_FORMAT_MACROS
#include <inttypes.h>

#define DMA_REGS_BASE_ADDR	0x60000000

#define RESMEM_BASE_ADDR	0x30000000
#define RESMEM_LENGTH		0x10000000

/* registers of the DMA engine at 0x60000000 */
typedef struct {
/* +0x00 */ uint32_t mm2s_dmacr;
/* +0x04 */ uint32_t mm2s_dmasr;
/* +0x08 */ uint32_t mm2s_curdesc;
/* +0x0c */ uint32_t _res0;
/* +0x10 */ uint32_t mm2s_taildesc;
/* +0x14 */ uint32_t _res1[6];
/* +0x2c */ uint32_t sg_ctl;
/* +0x30 */ uint32_t s2mm_dmacr;
/* +0x34 */ uint32_t s2mm_dmasr;
/* +0x38 */ uint32_t s2mm_curdesc;
/* +0x3c */ uint32_t _res2;
/* +0x40 */ uint32_t s2mm_taildesc;
} __attribute__((packed)) dma_regs_t;

/* our registers, one page above the DMA's, i.e. at 0x60001000 */
typedef struct {
/* +0x00 */ uint32_t pl_design_id;
/* +0x04 */ uint32_t control;
/* +0x08 */ uint32_t frame_counter;
/* +0x0c */ uint32_t overflow_counter;
/* +0x10 */ uint32_t _res0;
/* +0x14 */ uint32_t last_sync;
} __attribute__((packed)) our_regs_t;

/* must be aligned to 0x40 bytes */
typedef struct {
/* +0x00 */ uint32_t nxtdesc;
/* +0x04 */ uint32_t _res0;
/* +0x08 */ uint32_t buffer_address;
/* +0x0c */ uint32_t _res1[3];
/* +0x18 */ uint32_t control;
/* +0x1c */ uint32_t status;
} __attribute__((packed)) desc_t;

#define DESC_BUFLEN_MAX		(1<<24)
#define DESC_BUFLEN_MASK	DESC_BUFLEN_MAX-1

#define DESC_CONTROL_TXEOF (1<<26)
#define DESC_CONTROL_TXSOF (1<<27)

#define DESC_CONTROL_RXEOF (1<<26)
#define DESC_CONTROL_RXSOF (1<<27)

#define DESC_STATUS_CMPLT  ((uint32_t) (1<<31))

int devmem_fd;
dma_regs_t *dma_regs;
our_regs_t *our_regs;
void *resmem_ptr;

void init_mmapings()
{
	devmem_fd = open("/dev/mem", O_RDWR|O_SYNC);
	if (devmem_fd < 0) err(1, "opening /dev/mem");

	dma_regs = (dma_regs_t *) mmap(NULL, 2*0x1000, PROT_READ|PROT_WRITE,
								   MAP_SHARED, devmem_fd, DMA_REGS_BASE_ADDR);
	if (dma_regs == MAP_FAILED) err(1, "mmaping registers");
	our_regs = (our_regs_t *) (((void *) dma_regs) + 0x1000);

	resmem_ptr = mmap(NULL, RESMEM_LENGTH, PROT_READ|PROT_WRITE,
					  MAP_SHARED, devmem_fd, RESMEM_BASE_ADDR);
	if (resmem_ptr == MAP_FAILED) err(1, "mmaping reserved memory");
}

void *phys_to_virt(uint32_t phys)
{
	if (phys == 0) return NULL;
	return resmem_ptr + (phys - RESMEM_BASE_ADDR);
}

uint32_t virt_to_phys(void *virt)
{
	if (virt == NULL) return 0;
	return RESMEM_BASE_ADDR + (uint32_t) (virt - resmem_ptr);
}

void desc_set_next(desc_t *desc, desc_t *next)
{
	assert((((uint32_t) next) & 0x3f) == 0); /* check alignment */
	desc->nxtdesc = virt_to_phys(next);
}

desc_t *desc_get_next(desc_t *desc)
{
	return phys_to_virt(desc->nxtdesc);
}

desc_t *desc_freelist_first, *desc_freelist_last;

void init_descriptors()
{
	desc_t *prev = NULL;

	/* devote the first 4kB of reserved memory to descriptors */
	void *p;
	for (p = resmem_ptr; p < resmem_ptr + 0x1000000; p += 0x40) {
		desc_t *desc = (desc_t *) p;
 
		if (prev != NULL) {
			desc_set_next(prev, desc);
		} else {
			desc_freelist_first = desc;
		}

		prev = desc;
	}

	desc_set_next(prev, NULL);
	desc_freelist_last = prev;
}

void desc_free(desc_t *desc)
{
	if (desc_freelist_last != NULL)
		desc_set_next(desc_freelist_last, desc);
	else
		desc_freelist_first = desc;

	desc_set_next(desc, NULL);
	desc_freelist_last = desc;
}

desc_t *desc_alloc()
{
	desc_t *ret = desc_freelist_first;

	if (ret == NULL)
		errx(1, "out of free descriptors");

	assert((desc_get_next(ret) == NULL) == (ret == desc_freelist_last));

	desc_freelist_first = desc_get_next(ret);
	if (ret == desc_freelist_last)
		desc_freelist_last = NULL;

	memset(ret, 0, sizeof(desc_t));
	return ret;
}

void ringbufcpy(void *rbstart, size_t rblen,
				size_t copyoff, size_t copylen, void *target)
{
	int piece;

	while (copylen > 0) {
		copyoff = (copyoff % rblen + rblen) % rblen;
		piece = copylen;
		if (copyoff + piece > rblen)
			piece = rblen - copyoff;
		memcpy(target, rbstart + copyoff, piece);
		copyoff += piece;
		target += piece;
		copylen -= piece;
	}
}

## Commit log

2019-02-20 A gnuradio schematics to read data and display waterfall.
2020-08-06 New image of mobile antenna array.
2020-08-14 Switch QT waterfall GUI to Fosphor waterfall.
2021-03-18 Correct number of antenna in station block schematics.
2021-07-25 Use of GUI Tabs. reorganising the fosfor windows to match antenna channels.
2022-02-14 Add glue-dev branch.
2022-02-16 Update block schematics.
2022-02-17 Update version of modules in block schematics.
2022-02-17 Improve power info in block schematics.
2022-04-10 Mark signal levels in block schematics.
